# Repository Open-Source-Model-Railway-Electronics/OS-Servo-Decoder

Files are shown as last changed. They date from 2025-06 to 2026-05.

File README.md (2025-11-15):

# OS-Servo-Decoder

The OS-Servo-Decoder is a simple and robust DCC accessory decoder designed for driving up to 8 servo motors. It supports modern model railroads with flexible configuration options, external relay modules for polarity switching (optional) and direct control using both input switches, DCC accessory commands and locomotive functions (F1–F8).

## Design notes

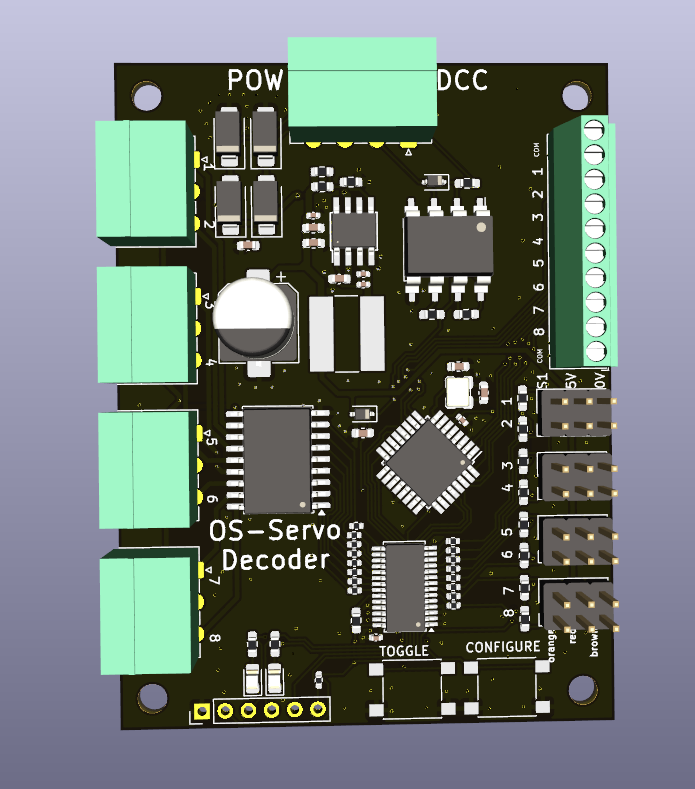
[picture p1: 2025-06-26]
hardware/OS-Servo-Decoder-8.png

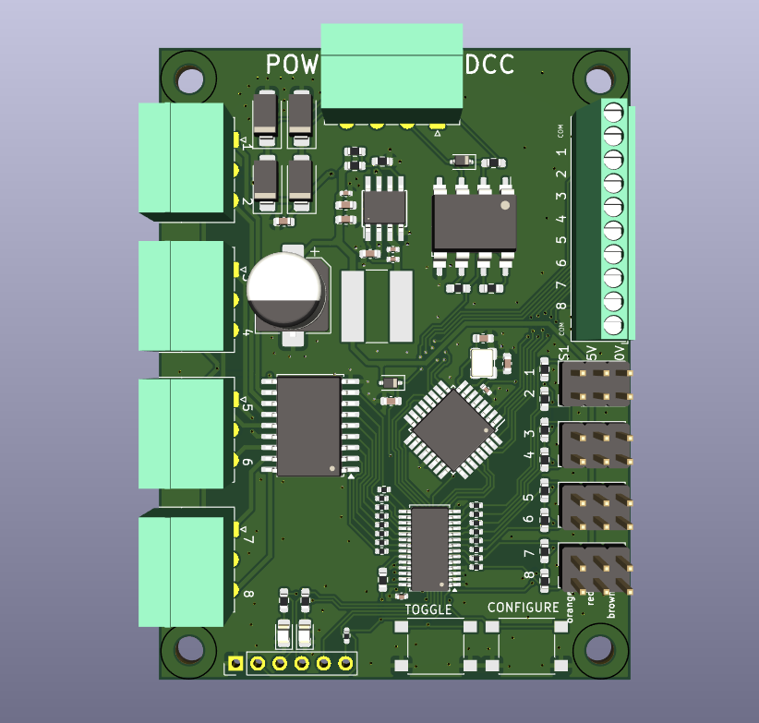
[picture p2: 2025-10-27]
releases/OS-Servo-Decoder-8.png

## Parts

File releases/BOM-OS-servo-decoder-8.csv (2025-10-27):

Comment | Designator | Footprint | LCSC
6N137 | U1001 | SOP-8_6.62x9.15mm_P2.54mm | C110020
Crystal_GND2 | Y201 | crystal_arduino | C13738
100nF | C501 | C_0603_1608Metric | C14663
ATmega328-A | U202 | TQFP-32_7x7mm_P0.8mm | C14877
22nF | C903 | C_0402_1005Metric | C1532
ULN2803A | U1101 | SOIC-18W_7.5x11.6mm_P1.27mm | C181731
1k | R1001 | R_0603_smalltext | C21190
1N4148WS | D1001,D401 | D_SOD-323 | C2128
150k | R903 | R_0603_1608Metric | C22807
220k | R901 | R_0603_1608Metric | C22961
220R | R1602,R1603,R1604,R1605,R1606,R1607,R1608,R1609,R1610,R1611,R1612,R1613,R1614,R1615,R1616,R1617 | R_0402_1005Metric | C25091
10k | R202 | R_0402_1005Metric_Pad0.72x0.64mm_HandSolder | C25744
10k | R1002,R1003,R1004,R1005,R1601,R701,R702,R801,R802,R904,R905 | R_0603_smalltext | C25804
PCA9685PW | U1601 | TSSOP-28_4.4x9.7mm_P0.65mm | C2678753
L | L901 | L_Bourns-SRN8040_8x8.15mm | C2929438
SW_Push | SW601,SW602 | tactile_SMD_6mm | C294567
MT2499A | U901 | TI_SO-PowerPAD-8 | C3007555
100nF | C1601,C202,C902,C906 | C_0402_1005Metric | C307331
12pF | C201,C203 | C_0603_1608Metric | C38523
6k2 | R201,R203 | R_0603_1608Metric_Pad0.98x0.95mm_HandSolder | C4260
20k | R902 | R_0603_1608Metric | C4328
22uF | C402,C901,C904,C905 | C_0603_1608Metric | C45783
1000uF | C401 | CP_Elec_8x10.5 | C5162347
Conn_02x03_Odd_Even | J1001,J701,J801,J901 | PinHeader_2x03_P2.54mm_Vertical | C65114
LED | D201,D202 | LED_0805_2012Metric_Pad1.15x1.40mm_HandSolder | C84256
SS53 | D501,D502,D503,D504 | D_SMA | C8678
Screw_Terminal_01x03 | J1301,J1401,J1501,J401 | PhoenixContact_MC_1,5_3-G-3.5_1x03_P3.50mm_Horizontal | C880573
FEMALE | J101 | PhoenixContact_MC_1,5_4-G-3.5_1x04_P3.50mm_Horizontal | C880574
Screw_Terminal_01x10 | J501 | TerminalBlock_Phoenix_MPT-0,5-10-2.54_1x10_P2.54mm_Horizontal

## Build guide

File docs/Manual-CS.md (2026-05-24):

> 🌐 &nbsp; [🇬🇧 EN](Manual-EN.md) &nbsp;|&nbsp; [🇩🇪 DE](Manual-DE.md) &nbsp;|&nbsp; [🇫🇷 FR](Manual-FR.md) &nbsp;|&nbsp; [🇳🇱 NL](Manual-NL.md) &nbsp;|&nbsp; [🇪🇸 ES](Manual-ES.md) &nbsp;|&nbsp; [🇮🇹 IT](Manual-IT.md) &nbsp;|&nbsp; [🇵🇱 PL](Manual-PL.md) &nbsp;|&nbsp; 🇨🇿 CS &nbsp;|&nbsp; [🇩🇰 DA](Manual-DA.md) &nbsp;|&nbsp; [🇳🇴 NO](Manual-NO.md) &nbsp;|&nbsp; [🇸🇪 SV](Manual-SV.md) &nbsp;|&nbsp; [🇭🇺 HU](Manual-HU.md) &nbsp;|&nbsp; [🇵🇹 PT](Manual-PT.md)

# Manuál dekodérů OS-Servo

## 📘 Úvod
OS-Servo-Decoder je jednoduchý a robustní DCC příslušenský dekodér navržený pro pohon až 8 servomotorů. Podporuje moderní modelové železnice s flexibilními možnostmi konfigurace, externími relé moduly pro přepínání polarity (volitelné) a přímé ovládání pomocí vstupních přepínačů, DCC příslušenských příkazů i lokomotivních funkcí (F1–F8).

---

## 📚 Obsah

- [Manuál dekodérů OS-Servo](#manuál-dekodérů-os-servo)
  - [📘 Úvod](#-úvod)
  - [📚 Obsah](#-obsah)
  - [🔧 Vlastnosti](#-vlastnosti)
  - [🔌 Připojení dekodéru](#-připojení-dekodéru)
  - [💪 Ovládání výstupů servo](#-ovládání-výstupů-servo)
  - [🛠️ Konfigurační režim DCC](#️-konfigurační-režim-dcc)
  - [🛠️ Konfigurační režim tlačítek](#️-konfigurační-režim-tlačítek)
  - [🌟 Ukládání poloh serva](#-ukládání-poloh-serva)
  - [🚗 Režimy lokomotivních funkcí](#-režimy-lokomotivních-funkcí)
  - [⚖️ Adresový offset](#️-adresový-offset)
  - [⏰ Režim automatického přepínání](#-režim-automatického-přepínání)
  - [📊 Souhrn](#-souhrn)

---

## 🔧 Vlastnosti
- Ovládá až 8 serv  
- Používá zásuvné šroubové svorky pro snadné zapojení  
- Externí relé moduly  
- Plná podpora:  
  - Standardní pohyb výhybky  
  - Přepínání polarity (kde je podporováno)  
  - Nastavitelné krajní polohy serva (pomocí tlačítek)  
- Samostatná konfigurace: není potřeba PC, CV ani programátor  
- Volitelné ovládání lokomotivními funkcemi DCC (F1–F18)  
- Podporuje Roco 4-adresový offset  

---

## 🔌 Připojení dekodéru

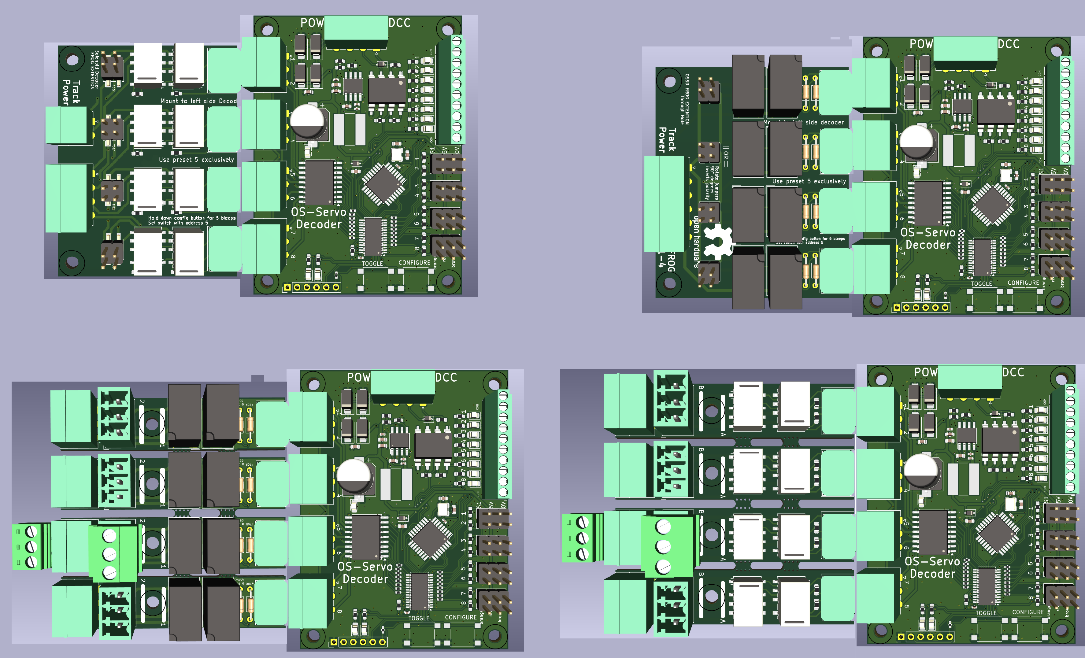
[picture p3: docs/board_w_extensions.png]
OS-Servo-Decoder-8 s různými konfiguracemi rozšiřujících relé


*OS-Servo-Decoder-8 zobrazený s různými zapojenými rozšiřujícími relé moduly (vlevo nahoře: aretační relé; vpravo nahoře: víceúčelová relé; dole: kombinace s připojenými servy).*

OS-Servo-Decoder-8 používá stejné schéma zapojení jako OS-Solenoid-Decoder:

- **Horní záhlaví (POW / DCC):** Připojte kolejové napětí DCC nebo DC napájení (max. 19 V)
- ⚠️ **Důležité:** Nepoužívejte AC napětí — poškodí dekodér
- **Záhlaví pro serva (pravá strana):** Připojte každý servomotor ke 3-pinovému konektoru
  - Standardní zapojení: **GND — +5 V — Signál**
- **Relé konektory (levá strana):** A, COM, B — pro rozšiřující OS relé moduly

---

## 💪 Ovládání výstupů servo

Každý výstup serva je řízen DCC příslušenskou adresou. Když dekodér přijme DCC příkaz pro přiřazenou adresu, plynule posune servo do uložené polohy pro daný stav příkazu (PŘÍMÝ nebo OBLOUK).

- Odeslání příkazu **PŘÍMÝ** přesune servo do uložené přímé krajní polohy.
- Odeslání příkazu **OBLOUK** přesune servo do uložené obloukové krajní polohy.
- Pokud jsou namontovány rozšiřující relé moduly, kontakty relé se přepínají synchronně se servem pro polarizaci srdcovky.

Krajní polohy serva se ukládají pomocí funkčních kláves lokomotivy — viz [Ukládání poloh serva](#-ukládání-poloh-serva) níže.

---

## 🛠️ Konfigurační režim DCC

Dekodér podporuje konfigurační režim, který funguje zcela z vašeho DCC ovladače — není potřeba počítač ani programátor CV.

Pro vstup do konfiguračního režimu vyberte na ovladači adresu lokomotivy **9999** a nastavte **F0, F1 a F2 vše na VYPNUTO**. Dekodér vstoupí do konfiguračního režimu a přijme příkazy funkčních kláves.

Po vstupu do konfiguračního režimu použijte funkční klávesy (F1–F8) pro nastavení možností popsaných v níže uvedených sekcích. Stiskněte **F0 = VYPNUTO** pro ukončení a návrat do normálního provozu.

---

## 🛠️ Konfigurační režim tlačítek

Deska má dvě fyzická tlačítka: **CONFIGURE** (KONFIGUROVAT) a **TOGGLE** (PŘEPNOUT).

- **CONFIGURE** — přímo vstoupí do konfiguračního režimu bez potřeby ovladače. Dekodér reaguje LED signalizací indikující aktivní nastavení.
- **TOGGLE** — ručně přepne aktuálně vybraný výstup serva mezi jeho dvěma uloženými polohami. Užitečné pro testování pohybu a nastavení krajních poloh.

---

## 🌟 Ukládání poloh serva
V provozním režimu použijte tyto funkce k programování:

- **F1 = ZAP ➔** Uloží aktuální polohu jako *OBLOUK*  
- **F2 = ZAP ➔** Uloží aktuální polohu jako *PŘÍMÝ*  
- **F3 = ZAP ➔** Invertuje relé srdcovky *(pouze model s 6 relé)*  
- **F0 = VYP ➔** Ukončí provozní režim  

---

## 🚗 Režimy lokomotivních funkcí
V konfiguračním režimu můžete zvolit ovládání dekodéru pomocí lokomotivních funkčních kláves místo příslušenských příkazů.

- **F4 = ZAP ➔** Zakáže ovládání lokomotivou *(výchozí)*  
- **F5 = ZAP ➔** Povolí režim lokomotivních funkcí *(F1–F8)* — používá 1 adresu  
- **F6 = ZAP ➔** Povolí 4-funkční režim *(F1–F4)* — používá 2 adresy  

To umožňuje velmi rychlé přepínání pomocí ovladačů jako Roco Lokmaus nebo Multimaus.

---

## ⚖️ Adresový offset
Pro kompenzaci offsetu Roco o 4 použijte:

- **F7 = ZAP ➔** Povolí 4-adresový offset  

---

## ⏰ Režim automatického přepínání
Povolte automatické přepínání vybraného motoru:

- **F8 = ZAP ➔** Motor se přepíná každých 5 sekund  
  - Rychlost je řízena ovladačem  
  - Směr ovladače nehraje roli  
  - Ovladač 0 = pomalu, Maximum = rychle  

V tomto režimu motor již není řízen funkčními klávesami ovladače.

---

## 📊 Souhrn
- Použijte tlačítka pro přímé nastavení a nastavení serva  
- Použijte DCC adresu lokomotivy **9999** s **F0, F1, F2 VYPNUTO** pro vstup do konfiguračního režimu  
- Použijte **F1/F2** pro uložení poloh serva  
- Použijte **F4–F8** pro povolení ovládání lokomotivními funkcemi, adresového offsetu nebo režimů přepínání  

Všechny OS-Servo-Decoders sdílejí toto rozhraní a logiku.  
Není potřeba počítač. Žádné CV. Stačí zapojit, adresovat a spustit.

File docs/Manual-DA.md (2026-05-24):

> 🌐 &nbsp; [🇬🇧 EN](Manual-EN.md) &nbsp;|&nbsp; [🇩🇪 DE](Manual-DE.md) &nbsp;|&nbsp; [🇫🇷 FR](Manual-FR.md) &nbsp;|&nbsp; [🇳🇱 NL](Manual-NL.md) &nbsp;|&nbsp; [🇪🇸 ES](Manual-ES.md) &nbsp;|&nbsp; [🇮🇹 IT](Manual-IT.md) &nbsp;|&nbsp; [🇵🇱 PL](Manual-PL.md) &nbsp;|&nbsp; [🇨🇿 CS](Manual-CS.md) &nbsp;|&nbsp; 🇩🇰 DA &nbsp;|&nbsp; [🇳🇴 NO](Manual-NO.md) &nbsp;|&nbsp; [🇸🇪 SV](Manual-SV.md) &nbsp;|&nbsp; [🇭🇺 HU](Manual-HU.md) &nbsp;|&nbsp; [🇵🇹 PT](Manual-PT.md)

# OS-Servo-Decoders Manual

## 📘 Introduktion
OS-Servo-Decoder er en enkel og robust DCC-tilbehørsdekoder designet til at drive op til 8 servomotorer. Den understøtter moderne modeljernbaner med fleksible konfigurationsmuligheder, eksterne relæmoduler til polaritetsskift (valgfrit) og direkte styring ved hjælp af både indgangsafbrydere, DCC-tilbehørskommandoer og lokomotivfunktioner (F1–F8).

---

## 📚 Indholdsfortegnelse

- [OS-Servo-Decoders Manual](#os-servo-decoders-manual)
  - [📘 Introduktion](#-introduktion)
  - [📚 Indholdsfortegnelse](#-indholdsfortegnelse)
  - [🔧 Egenskaber](#-egenskaber)
  - [🔌 Tilslutning af dekoderen](#-tilslutning-af-dekoderen)
  - [💪 Styring af servo-udgange](#-styring-af-servo-udgange)
  - [🛠️ DCC-konfigurationstilstand](#️-dcc-konfigurationstilstand)
  - [🛠️ Knapkonfigurationstilstand](#️-knapkonfigurationstilstand)
  - [🌟 Lagring af servo-positioner](#-lagring-af-servo-positioner)
  - [🚗 Lokomotivfunktionstilstande](#-lokomotivfunktionstilstande)
  - [⚖️ Adresseforskydning](#️-adresseforskydning)
  - [⏰ Auto-toggle-tilstand](#-auto-toggle-tilstand)
  - [📊 Oversigt](#-oversigt)

---

## 🔧 Egenskaber
- Styrer op til 8 servoer  
- Bruger tilsluttbare skrueterminaler til nem kabeltrækning  
- Eksterne relæmoduler  
- Understøtter fuldt ud:  
  - Standard sporskiftebevægelse  
  - Polaritetsskift (hvor understøttet)  
  - Justerbare servo-endpositioner (via knapper)  
- Selvstændig konfiguration: ingen PC, CV'er eller programmere påkrævet  
- Valgfri DCC-lokomotivfunktionsstyring (F1–F18)  
- Understøtter Roco 4-adresse-forskydning  

---

## 🔌 Tilslutning af dekoderen

OS-Servo-Decoder-8 med forskellige relæudvidelseskonfigurationer

*OS-Servo-Decoder-8 vist med forskellige relæudvidelsesmoduler tilsluttet (øverst til venstre: selvholdende relæer; øverst til højre: general-purpose relæer; nederst: kombinationer med servoer tilsluttet).*

OS-Servo-Decoder-8 bruger det samme kabeltrækningslayout som OS-Solenoid-Decoder:

- **Øvre header (POW / DCC):** Forbind enten DCC-skinnesænkning eller en DC-strømforsyning (maks. 19 V)
- ⚠️ **Vigtigt:** Brug ikke AC-spænding — dette vil beskadige dekoderen
- **Servo-headere (højre side):** Forbind hver servomotor til 3-pin-stikket
  - Standard pinout: **GND — +5 V — Signal**
- **Relæstik (venstre side):** A, COM, B — til OS-relæudvidelsesmoduler

---

## 💪 Styring af servo-udgange

Hver servo-udgang styres af en DCC-tilbehørsadresse. Når dekoderen modtager en DCC-kommando for en tildelt adresse, bevæger den servoens jævnt til den lagrede position for den kommandotilstand (LIGE eller KURVET).

- Afsendelse af **LIGE**-kommandoen bevæger servoens til dens lagrede lige endposition.
- Afsendelse af **KURVET**-kommandoen bevæger servoens til dens lagrede kurvede endposition.
- Hvis relæudvidelsesmoduler er monteret, skifter relækontakterne synkront med servoens til hjertestykke-polarisering.

Servo-endpositioner lagres ved hjælp af lokomotivfunktionsknapper — se [Lagring af servo-positioner](#-lagring-af-servo-positioner) nedenfor.

---

## 🛠️ DCC-konfigurationstilstand

Dekoderen understøtter en konfigurationstilstand, der fungerer udelukkende fra din DCC-styreenhed — ingen computer, ingen CV-programmer påkrævet.

For at gå ind i konfigurationstilstand, vælg lokomotivadresse **9999** på din styreenhed og sæt **F0, F1 og F2 alle til FRA**. Dekoderen vil gå ind i konfigurationstilstand og acceptere funktionstastskommandoer.

Når du er i konfigurationstilstand, bruges funktionstasterne (F1–F8) til at indstille muligheder som beskrevet i afsnittene nedenfor. Tryk på **F0 = FRA** for at afslutte og vende tilbage til normal drift.

---

## 🛠️ Knapkonfigurationstilstand

Kortet har to fysiske knapper: **CONFIGURE** og **TOGGLE**.

- **CONFIGURE** — går direkte ind i konfigurationstilstand uden behov for en styreenhed. Dekoderen reagerer med LED-tilbagemelding, der angiver den aktive indstilling.
- **TOGGLE** — skifter manuelt den aktuelt valgte servo-udgang mellem dens to lagrede positioner. Nyttigt til test af bevægelse og justering af endpositioner.

---

## 🌟 Lagring af servo-positioner
Mens du er i Kørselstilstand, brug disse funktioner til at programmere:

- **F1 = TIL ➔** Gem aktuel position som *KURVET*  
- **F2 = TIL ➔** Gem aktuel position som *LIGE*  
- **F3 = TIL ➔** Inverter frog-relæet *(kun 6-relæ-model)*  
- **F0 = FRA ➔** Afslut kørselstilstand  

---

## 🚗 Lokomotivfunktionstilstande
I konfigurationstilstand kan du vælge at styre dekoderen ved hjælp af lokomotivfunktionsknapper i stedet for tilbehørskommandoer.

- **F4 = TIL ➔** Deaktiver lokomotivsstyring *(standard)*  
- **F5 = TIL ➔** Aktiver lokomotivsfunktionstilstand *(F1–F8)* — bruger 1 adresse  
- **F6 = TIL ➔** Aktiver 4-funktionstilstand *(F1–F4)* — bruger 2 adresser  

Dette muliggør ultrahurtig skift ved brug af styrenheder som Roco Lokmaus eller Multimaus.

---

## ⚖️ Adresseforskydning
For at kompensere for Rocos forskydning på 4, brug:

- **F7 = TIL ➔** Aktiver 4-adresse-forskydning  

---

## ⏰ Auto-toggle-tilstand
Aktiver automatisk toggling af en valgt motor:

- **F8 = TIL ➔** Motor skifter hvert 5. sekund  
  - Hastighed styres af styreenheden  
  - Styrenheds-retning er ligegyldig  
  - Styreenhed 0 = langsom, Maks = hurtig  

I denne tilstand er motoren ikke længere slavebundet til styrenheds-funktionstaster.

---

## 📊 Oversigt
- Brug knapperne til direkte opsætning og servo-justering  
- Brug DCC-lokomotivadresse **9999** med **F0, F1, F2 FRA** for at gå ind i konfigurationstilstand  
- Brug **F1/F2** til at lagre servo-positioner  
- Brug **F4–F8** til at aktivere lokomotivfunktionsstyring, adresseforskydning eller toggle-tilstande  

Alle OS-Servo-dekodere deler denne grænseflade og logik.  
Ingen computer påkrævet. Ingen CV'er. Bare kabelforbind den, adressér den og kør.

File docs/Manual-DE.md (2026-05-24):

> 🌐 &nbsp; [🇬🇧 EN](Manual-EN.md) &nbsp;|&nbsp; 🇩🇪 DE &nbsp;|&nbsp; [🇫🇷 FR](Manual-FR.md) &nbsp;|&nbsp; [🇳🇱 NL](Manual-NL.md) &nbsp;|&nbsp; [🇪🇸 ES](Manual-ES.md) &nbsp;|&nbsp; [🇮🇹 IT](Manual-IT.md) &nbsp;|&nbsp; [🇵🇱 PL](Manual-PL.md) &nbsp;|&nbsp; [🇨🇿 CS](Manual-CS.md) &nbsp;|&nbsp; [🇩🇰 DA](Manual-DA.md) &nbsp;|&nbsp; [🇳🇴 NO](Manual-NO.md) &nbsp;|&nbsp; [🇸🇪 SV](Manual-SV.md) &nbsp;|&nbsp; [🇭🇺 HU](Manual-HU.md) &nbsp;|&nbsp; [🇵🇹 PT](Manual-PT.md)

# OS-Servo-Decoder Handbuch

## 📘 Einführung
Der OS-Servo-Decoder ist ein einfacher und robuster DCC-Zubehördecoder für die Steuerung von bis zu 8 Servomotoren. Er unterstützt moderne Modellbahnen mit flexiblen Konfigurationsmöglichkeiten, externen Relaismodulen für Polaritätsumschaltung (optional) und direkter Steuerung über Eingangsschalter, DCC-Zubehörbefehle und Lokfunktionen (F1–F8).

---

## 📚 Inhaltsverzeichnis

- [OS-Servo-Decoder Handbuch](#os-servo-decoder-handbuch)
  - [📘 Einführung](#-einführung)
  - [📚 Inhaltsverzeichnis](#-inhaltsverzeichnis)
  - [🔧 Merkmale](#-merkmale)
  - [🔌 Anschließen des Decoders](#-anschließen-des-decoders)
  - [💪 Steuerung der Servoausgänge](#-steuerung-der-servoausgänge)
  - [🛠️ DCC-Konfigurationsmodus](#️-dcc-konfigurationsmodus)
  - [🛠️ Tasten-Konfigurationsmodus](#️-tasten-konfigurationsmodus)
  - [🌟 Speichern von Servopositionen](#-speichern-von-servopositionen)
  - [🚗 Lokfunktionsmodi](#-lokfunktionsmodi)
  - [⚖️ Adress-Offset](#️-adress-offset)
  - [⏰ Automatischer Umschaltmodus](#-automatischer-umschaltmodus)
  - [📊 Zusammenfassung](#-zusammenfassung)

---

## 🔧 Merkmale
- Steuert bis zu 8 Servos  
- Verwendet steckbare Schraubklemmen für einfache Verdrahtung  
- Externe Relaismodule  
- Vollständige Unterstützung für:  
  - Standardmäßige Weichenbewegung  
  - Polaritätsumschaltung (wo unterstützt)  
  - Einstellbare Servo-Endpositionen (über Tasten)  
- Eigenständige Konfiguration: kein PC, keine CVs oder Programmierer erforderlich  
- Optionale DCC-Lokfunktionssteuerung (F1–F18)  
- Unterstützt Roco 4-Adress-Offset  

---

## 🔌 Anschließen des Decoders

OS-Servo-Decoder-8 mit verschiedenen Relaiserweiterungs-Konfigurationen

*Der OS-Servo-Decoder-8 mit verschiedenen eingesteckten Relaiserweiterungsmodulen (oben links: bistabile Relais; oben rechts: Universalrelais; unten: Kombinationen mit angeschlossenen Servos).*

Der OS-Servo-Decoder-8 verwendet dasselbe Verdrahtungsschema wie der OS-Solenoid-Decoder:

- **Obere Stiftleiste (POW / DCC):** Entweder DCC-Gleisspannung oder eine DC-Stromversorgung anschließen (max. 19 V)
- ⚠️ **Wichtig:** Keine Wechselspannung verwenden — dies beschädigt den Decoder
- **Servo-Stiftleisten (rechte Seite):** Jeden Servomotor an den 3-poligen Stecker anschließen
  - Standardbelegung: **GND — +5 V — Signal**
- **Relais-Stecker (linke Seite):** A, COM, B — für OS-Relaiserweiterungsmodule

---

## 💪 Steuerung der Servoausgänge

Jeder Servoausgang wird durch eine DCC-Zubehöradresse gesteuert. Wenn der Decoder einen DCC-Befehl für eine zugewiesene Adresse empfängt, bewegt er den Servo gleichmäßig zur gespeicherten Position für diesen Befehlszustand (GERADE oder GEBOGEN).

- Das Senden des **GERADE**-Befehls bewegt den Servo zu seiner gespeicherten geraden Endposition.
- Das Senden des **GEBOGEN**-Befehls bewegt den Servo zu seiner gespeicherten gebogenen Endposition.
- Wenn Relaiserweiterungsmodule eingebaut sind, schalten die Relaiskontakte synchron mit dem Servo für die Herzstück-Polarisierung.

Servo-Endpositionen werden mit Lokfunktionstasten gespeichert — siehe [Speichern von Servopositionen](#-speichern-von-servopositionen) unten.

---

## 🛠️ DCC-Konfigurationsmodus

Der Decoder unterstützt einen Konfigurationsmodus, der vollständig über dein DCC-Fahrgerät funktioniert — kein Computer, kein CV-Programmierer erforderlich.

Um den Konfigurationsmodus aufzurufen, Lokadresse **9999** am Fahrgerät wählen und **F0, F1 und F2 alle auf AUS** stellen. Der Decoder wechselt in den Konfigurationsmodus und akzeptiert Funktionstastenbefehle.

Im Konfigurationsmodus die Funktionstasten (F1–F8) verwenden, um Optionen wie in den folgenden Abschnitten beschrieben einzustellen. **F0 = AUS** drücken, um zu beenden und zum Normalbetrieb zurückzukehren.

---

## 🛠️ Tasten-Konfigurationsmodus

Die Platine hat zwei physische Tasten: **CONFIGURE** und **TOGGLE**.

- **CONFIGURE** — wechselt direkt in den Konfigurationsmodus, ohne ein Fahrgerät zu benötigen. Der Decoder antwortet mit LED-Feedback, das die aktive Einstellung anzeigt.
- **TOGGLE** — schaltet den aktuell ausgewählten Servoausgang manuell zwischen seinen beiden gespeicherten Positionen um. Nützlich zum Testen der Bewegung und zum Anpassen der Endpositionen.

---

## 🌟 Speichern von Servopositionen
Im Fahrmodus diese Funktionen zum Programmieren verwenden:

- **F1 = EIN ➔** Aktuelle Position als *GEBOGEN* speichern  
- **F2 = EIN ➔** Aktuelle Position als *GERADE* speichern  
- **F3 = EIN ➔** Frog-Relais invertieren *(nur 6-Relais-Modell)*  
- **F0 = AUS ➔** Fahrmodus beenden  

---

## 🚗 Lokfunktionsmodi
Im Konfigurationsmodus kann gewählt werden, den Decoder über Lokfunktionstasten anstelle von Zubehörbefehlen zu steuern.

- **F4 = EIN ➔** Lok-Steuerung deaktivieren *(Standard)*  
- **F5 = EIN ➔** Lokfunktionsmodus aktivieren *(F1–F8)* — verwendet 1 Adresse  
- **F6 = EIN ➔** 4-Funktions-Modus aktivieren *(F1–F4)* — verwendet 2 Adressen  

Dies ermöglicht ultraschnelles Schalten mit Fahrgeräten wie Roco Lokmaus oder Multimaus.

---

## ⚖️ Adress-Offset
Um Rocos Offset von 4 zu kompensieren, verwenden:

- **F7 = EIN ➔** 4-Adress-Offset aktivieren  

---

## ⏰ Automatischer Umschaltmodus
Automatisches Umschalten eines ausgewählten Motors aktivieren:

- **F8 = EIN ➔** Motor schaltet alle 5 Sekunden um  
  - Geschwindigkeit wird durch das Fahrgerät gesteuert  
  - Fahrtrichtung des Fahrgeräts spielt keine Rolle  
  - Fahrgerät 0 = langsam, Maximum = schnell  

In diesem Modus ist der Motor nicht mehr an die Funktionstaten des Fahrgeräts gebunden.

---

## 📊 Zusammenfassung
- Tasten für direkte Einrichtung und Servo-Anpassung verwenden  
- DCC-Lokadresse **9999** mit **F0, F1, F2 AUS** verwenden, um den Konfigurationsmodus aufzurufen  
- **F1/F2** zum Speichern von Servopositionen verwenden  
- **F4–F8** zum Aktivieren von Lokfunktionssteuerung, Adress-Offset oder Umschaltmodi verwenden  

Alle OS-Servo-Decoder teilen diese Schnittstelle und Logik.  
Kein Computer erforderlich. Keine CVs. Einfach verkabeln, adressieren und fahren.

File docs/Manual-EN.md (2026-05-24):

> 🌐 &nbsp; 🇬🇧 EN &nbsp;|&nbsp; [🇩🇪 DE](Manual-DE.md) &nbsp;|&nbsp; [🇫🇷 FR](Manual-FR.md) &nbsp;|&nbsp; [🇳🇱 NL](Manual-NL.md) &nbsp;|&nbsp; [🇪🇸 ES](Manual-ES.md) &nbsp;|&nbsp; [🇮🇹 IT](Manual-IT.md) &nbsp;|&nbsp; [🇵🇱 PL](Manual-PL.md) &nbsp;|&nbsp; [🇨🇿 CS](Manual-CS.md) &nbsp;|&nbsp; [🇩🇰 DA](Manual-DA.md) &nbsp;|&nbsp; [🇳🇴 NO](Manual-NO.md) &nbsp;|&nbsp; [🇸🇪 SV](Manual-SV.md) &nbsp;|&nbsp; [🇭🇺 HU](Manual-HU.md) &nbsp;|&nbsp; [🇵🇹 PT](Manual-PT.md)

# OS-Servo-Decoders Manual

## 📘 Introduction
The OS-Servo-Decoder is a simple and robust DCC accessory decoder designed for driving up to 8 servo motors. It supports modern model railroads with flexible configuration options, external relay modules for polarity switching (optional) and direct control using both input switches, DCC accessory commands and locomotive functions (F1–F8).

---

## 📚 Table of Contents

- [OS-Servo-Decoders Manual](#os-servo-decoders-manual)
  - [📘 Introduction](#-introduction)
  - [📚 Table of Contents](#-table-of-contents)
  - [🔧 Features](#-features)
  - [🔌 Connecting the Decoder](#-connecting-the-decoder)
  - [💪 Controlling the Servo Outputs](#-controlling-the-servo-outputs)
  - [🛠️ DCC Configuration Mode](#️-dcc-configuration-mode)
  - [🛠️ Button Configuration Mode](#️-button-configuration-mode)
  - [🌟 Storing Servo Positions](#-storing-servo-positions)
  - [🚗 Loco Function Modes](#-loco-function-modes)
  - [⚖️ Address Offset](#️-address-offset)
  - [⏰ Auto-Toggle Mode](#-auto-toggle-mode)
  - [📊 Summary](#-summary)

---

## 🔧 Features
- Controls up to 8 servos  
- Uses pluggable screw terminals for easy wiring  
- External relay modules  
- Fully supports:  
  - Standard turnout movement  
  - Polarity switching (where supported)  
  - Adjustable servo end positions (via buttons)  
- Standalone configuration: no PC, CVs or programmers required  
- Optional DCC locomotive function control (F1–F18)  
- Supports Roco 4-address offset  

---

## 🔌 Connecting the Decoder

OS-Servo-Decoder-8 with different relay extension configurations

*The OS-Servo-Decoder-8 shown with various relay extension modules plugged in (top-left: latching relays; top-right: general-purpose relays; bottom: combinations with servos connected).*

The OS-Servo-Decoder-8 uses the same wiring layout as the OS-Solenoid-Decoder:

- **Top header (POW / DCC):** Connect either DCC track voltage or a DC power supply (max 19 V)
- ⚠️ **Important:** Do not use AC voltage — this will damage the decoder
- **Servo headers (right side):** Connect each servo motor to the 3-pin connector
  - Standard pinout: **GND — +5 V — Signal**
- **Relay connectors (left side):** A, COM, B — for OS relay extension modules

---

## 💪 Controlling the Servo Outputs

Each servo output is controlled by a DCC accessory address. When the decoder receives a DCC command for an assigned address, it moves the servo smoothly to the stored position for that command state (STRAIGHT or CURVED).

- Sending the **STRAIGHT** command moves the servo to its stored straight end position.
- Sending the **CURVED** command moves the servo to its stored curved end position.
- If relay extension modules are fitted, the relay contacts switch in sync with the servo for frog polarization.

Servo end positions are stored using loco function keys — see [Storing Servo Positions](#-storing-servo-positions) below.

---

## 🛠️ DCC Configuration Mode

The decoder supports a configuration mode that works entirely from your DCC throttle — no computer, no CV programmer required.

To enter configuration mode, select loco address **9999** on your throttle and set **F0, F1, and F2 all to OFF**. The decoder will enter config mode and accept function key commands.

Once in config mode, use the function keys (F1–F8) to set options as described in the sections below. Press **F0 = OFF** to exit and return to normal operation.

---

## 🛠️ Button Configuration Mode

The board has two physical buttons: **CONFIGURE** and **TOGGLE**.

- **CONFIGURE** — enters configuration mode directly, without needing a throttle. The decoder responds with LED feedback indicating the active setting.
- **TOGGLE** — manually toggles the currently selected servo output between its two stored positions. Useful for testing movement and adjusting end positions.

---

## 🌟 Storing Servo Positions
While in Run Mode, use these functions to program:

- **F1 = ON ➔** Save current position as *CURVED*  
- **F2 = ON ➔** Save current position as *STRAIGHT*  
- **F3 = ON ➔** Invert frog relay *(6-relay model only)*  
- **F0 = OFF ➔** Exit Run Mode  

---

## 🚗 Loco Function Modes
In Config Mode, you can choose to control the decoder using loco function keys instead of accessory commands.

- **F4 = ON ➔** Disable loco control *(default)*  
- **F5 = ON ➔** Enable loco function mode *(F1–F8)* — uses 1 address  
- **F6 = ON ➔** Enable 4-function mode *(F1–F4)* — uses 2 addresses  

This allows ultra-fast switching using throttles like Roco Lokmaus or Multimaus.

---

## ⚖️ Address Offset
To compensate for Roco’s offset of 4, use:

- **F7 = ON ➔** Enable 4-address offset  

---

## ⏰ Auto-Toggle Mode
Enable auto-toggling of a selected motor:

- **F8 = ON ➔** Motor toggles every 5 seconds  
  - Speed is controlled by throttle  
  - Throttle direction does not matter  
  - Throttle 0 = slow, Max = fast  

In this mode, the motor is no longer slaved to throttle function keys.

---

## 📊 Summary
- Use the buttons for direct setup and servo adjustment  
- Use DCC loco address **9999** with **F0, F1, F2 OFF** to enter config mode  
- Use **F1/F2** to store servo positions  
- Use **F4–F8** to enable loco function control, address offset or toggle modes  

All OS-Servo-Decoders share this interface and logic.  
No computer needed. No CVs. Just wire it, address it, and run it.

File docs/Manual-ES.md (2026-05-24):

> 🌐 &nbsp; [🇬🇧 EN](Manual-EN.md) &nbsp;|&nbsp; [🇩🇪 DE](Manual-DE.md) &nbsp;|&nbsp; [🇫🇷 FR](Manual-FR.md) &nbsp;|&nbsp; [🇳🇱 NL](Manual-NL.md) &nbsp;|&nbsp; 🇪🇸 ES &nbsp;|&nbsp; [🇮🇹 IT](Manual-IT.md) &nbsp;|&nbsp; [🇵🇱 PL](Manual-PL.md) &nbsp;|&nbsp; [🇨🇿 CS](Manual-CS.md) &nbsp;|&nbsp; [🇩🇰 DA](Manual-DA.md) &nbsp;|&nbsp; [🇳🇴 NO](Manual-NO.md) &nbsp;|&nbsp; [🇸🇪 SV](Manual-SV.md) &nbsp;|&nbsp; [🇭🇺 HU](Manual-HU.md) &nbsp;|&nbsp; [🇵🇹 PT](Manual-PT.md)

# Manual del OS-Servo-Decoder

## 📘 Introducción
El OS-Servo-Decoder es un decodificador de accesorios DCC sencillo y robusto diseñado para accionar hasta 8 servomotores. Ofrece opciones de configuración flexibles para maquetas de ferrocarril modernas, módulos de relé externos para conmutación de polaridad (opcional) y control directo mediante interruptores de entrada, comandos de accesorio DCC y funciones de locomotora (F1–F8).

---

## 📚 Tabla de Contenidos

- [Manual del OS-Servo-Decoder](#manual-del-os-servo-decoder)
  - [📘 Introducción](#-introducción)
  - [📚 Tabla de Contenidos](#-tabla-de-contenidos)
  - [🔧 Características](#-características)
  - [🔌 Conexión del Decodificador](#-conexión-del-decodificador)
  - [💪 Control de las Salidas de Servo](#-control-de-las-salidas-de-servo)
  - [🛠️ Modo de Configuración DCC](#️-modo-de-configuración-dcc)
  - [🛠️ Modo de Configuración por Botón](#️-modo-de-configuración-por-botón)
  - [🌟 Almacenamiento de Posiciones de Servo](#-almacenamiento-de-posiciones-de-servo)
  - [🚗 Modos de Función de Locomotora](#-modos-de-función-de-locomotora)
  - [⚖️ Desplazamiento de Dirección](#️-desplazamiento-de-dirección)
  - [⏰ Modo de Alternancia Automática](#-modo-de-alternancia-automática)
  - [📊 Resumen](#-resumen)

---

## 🔧 Características
- Controla hasta 8 servos  
- Utiliza bornes de tornillo enchufables para un cableado sencillo  
- Módulos de relé externos  
- Compatible completamente con:  
  - Movimiento estándar de agujas  
  - Conmutación de polaridad (donde sea compatible)  
  - Posiciones finales de servo ajustables (mediante botones)  
- Configuración autónoma: no requiere PC, CV ni programadores  
- Control opcional mediante funciones de locomotora DCC (F1–F18)  
- Compatible con el desplazamiento de 4 direcciones de Roco  

---

## 🔌 Conexión del Decodificador

OS-Servo-Decoder-8 con diferentes configuraciones de extensión de relé

*El OS-Servo-Decoder-8 mostrado con varios módulos de extensión de relé enchufados (arriba izquierda: relés enclavados; arriba derecha: relés de uso general; abajo: combinaciones con servos conectados).*

El OS-Servo-Decoder-8 utiliza el mismo esquema de cableado que el OS-Solenoid-Decoder:

- **Cabezal superior (POW / DCC):** Conecte la tensión de vía DCC o una fuente de alimentación DC (máx. 19 V)
- ⚠️ **Importante:** No use tensión AC — esto dañará el decodificador
- **Cabezales de servo (lado derecho):** Conecte cada servomotor al conector de 3 pines
  - Patillaje estándar: **GND — +5 V — Señal**
- **Conectores de relé (lado izquierdo):** A, COM, B — para módulos de extensión de relé OS

---

## 💪 Control de las Salidas de Servo

Cada salida de servo se controla mediante una dirección de accesorio DCC. Cuando el decodificador recibe un comando DCC para una dirección asignada, mueve el servo suavemente hasta la posición almacenada para ese estado de comando (RECTO o CURVO).

- El comando **RECTO** mueve el servo a su posición final recta almacenada.
- El comando **CURVO** mueve el servo a su posición final curva almacenada.
- Si hay módulos de extensión de relé instalados, los contactos del relé conmutan en sincronía con el servo para la polarización del frog.

Las posiciones finales del servo se almacenan usando las teclas de función de locomotora — véase [Almacenamiento de Posiciones de Servo](#-almacenamiento-de-posiciones-de-servo) a continuación.

---

## 🛠️ Modo de Configuración DCC

El decodificador admite un modo de configuración que funciona completamente desde su mando DCC — sin ordenador, sin programador de CV.

Para entrar en el modo de configuración, seleccione la dirección de locomotora **9999** en su mando y ponga **F0, F1 y F2 en OFF**. El decodificador entrará en el modo de configuración y aceptará comandos de tecla de función.

Una vez en el modo de configuración, use las teclas de función (F1–F8) para establecer opciones según se describe en las secciones siguientes. Pulse **F0 = OFF** para salir y volver al funcionamiento normal.

---

## 🛠️ Modo de Configuración por Botón

La placa tiene dos botones físicos: **CONFIGURE** y **TOGGLE**.

- **CONFIGURE** — entra en el modo de configuración directamente, sin necesidad de mando. El decodificador responde con indicación LED que muestra el ajuste activo.
- **TOGGLE** — alterna manualmente la salida de servo seleccionada actualmente entre sus dos posiciones almacenadas. Útil para probar el movimiento y ajustar las posiciones finales.

---

## 🌟 Almacenamiento de Posiciones de Servo
En el Modo de Funcionamiento, use estas funciones para programar:

- **F1 = ON ➔** Guardar posición actual como *CURVO*  
- **F2 = ON ➔** Guardar posición actual como *RECTO*  
- **F3 = ON ➔** Invertir el relé de frog *(solo modelo de 6 relés)*  
- **F0 = OFF ➔** Salir del Modo de Funcionamiento  

---

## 🚗 Modos de Función de Locomotora
En el Modo de Configuración, puede elegir controlar el decodificador usando teclas de función de locomotora en lugar de comandos de accesorio.

- **F4 = ON ➔** Deshabilitar control por locomotora *(predeterminado)*  
- **F5 = ON ➔** Habilitar modo de función de locomotora *(F1–F8)* — usa 1 dirección  
- **F6 = ON ➔** Habilitar modo de 4 funciones *(F1–F4)* — usa 2 direcciones  

Esto permite una conmutación ultrarrápida usando mandos como el Roco Lokmaus o el Multimaus.

---

## ⚖️ Desplazamiento de Dirección
Para compensar el desplazamiento de 4 de Roco, use:

- **F7 = ON ➔** Habilitar desplazamiento de 4 direcciones  

---

## ⏰ Modo de Alternancia Automática
Habilite la alternancia automática de un motor seleccionado:

- **F8 = ON ➔** El motor alterna cada 5 segundos  
  - La velocidad se controla con el regulador  
  - La dirección del regulador no importa  
  - Regulador 0 = lento, Máximo = rápido  

En este modo, el motor ya no está subordinado a las teclas de función del regulador.

---

## 📊 Resumen
- Use los botones para la configuración directa y el ajuste del servo  
- Use la dirección de locomotora DCC **9999** con **F0, F1, F2 en OFF** para entrar en el modo de configuración  
- Use **F1/F2** para almacenar las posiciones del servo  
- Use **F4–F8** para habilitar el control por función de locomotora, el desplazamiento de dirección o los modos de alternancia  

Todos los OS-Servo-Decoders comparten esta interfaz y lógica.  
No se necesita ordenador. Sin CV. Solo cable, dirección y puesta en marcha.

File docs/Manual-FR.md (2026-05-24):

> 🌐 &nbsp; [🇬🇧 EN](Manual-EN.md) &nbsp;|&nbsp; [🇩🇪 DE](Manual-DE.md) &nbsp;|&nbsp; 🇫🇷 FR &nbsp;|&nbsp; [🇳🇱 NL](Manual-NL.md) &nbsp;|&nbsp; [🇪🇸 ES](Manual-ES.md) &nbsp;|&nbsp; [🇮🇹 IT](Manual-IT.md) &nbsp;|&nbsp; [🇵🇱 PL](Manual-PL.md) &nbsp;|&nbsp; [🇨🇿 CS](Manual-CS.md) &nbsp;|&nbsp; [🇩🇰 DA](Manual-DA.md) &nbsp;|&nbsp; [🇳🇴 NO](Manual-NO.md) &nbsp;|&nbsp; [🇸🇪 SV](Manual-SV.md) &nbsp;|&nbsp; [🇭🇺 HU](Manual-HU.md) &nbsp;|&nbsp; [🇵🇹 PT](Manual-PT.md)

# Manuel des décodeurs OS-Servo

## 📘 Introduction
Le OS-Servo-Decoder est un décodeur DCC accessoire simple et robuste conçu pour piloter jusqu'à 8 servomoteurs. Il prend en charge les réseaux ferroviaires miniatures modernes avec des options de configuration flexibles, des modules relais externes pour la commutation de polarité (optionnels) et une commande directe via des interrupteurs d'entrée, des commandes DCC accessoire et des fonctions de locomotive (F1–F8).

---

## 📚 Table des matières

- [Manuel des décodeurs OS-Servo](#manuel-des-décodeurs-os-servo)
  - [📘 Introduction](#-introduction)
  - [📚 Table des matières](#-table-des-matières)
  - [🔧 Caractéristiques](#-caractéristiques)
  - [🔌 Connexion du décodeur](#-connexion-du-décodeur)
  - [💪 Commande des sorties servo](#-commande-des-sorties-servo)
  - [🛠️ Mode de configuration DCC](#️-mode-de-configuration-dcc)
  - [🛠️ Mode de configuration par bouton](#️-mode-de-configuration-par-bouton)
  - [🌟 Mémorisation des positions servo](#-mémorisation-des-positions-servo)
  - [🚗 Modes de fonctions de locomotive](#-modes-de-fonctions-de-locomotive)
  - [⚖️ Décalage d'adresse](#️-décalage-dadresse)
  - [⏰ Mode basculement automatique](#-mode-basculement-automatique)
  - [📊 Récapitulatif](#-récapitulatif)

---

## 🔧 Caractéristiques
- Commande jusqu'à 8 servos  
- Utilise des borniers à vis enfichables pour un câblage facile  
- Modules relais externes  
- Prend entièrement en charge :  
  - Le mouvement standard de l'aiguille  
  - La commutation de polarité (lorsque prise en charge)  
  - Les positions finales de servo réglables (via boutons)  
- Configuration autonome : aucun PC, CV ou programmateur requis  
- Commande optionnelle par fonctions de locomotive DCC (F1–F18)  
- Prend en charge le décalage d'adresse Roco de 4

---

## 🔌 Connexion du décodeur

OS-Servo-Decoder-8 avec différentes configurations d'extension relais

*Le OS-Servo-Decoder-8 présenté avec divers modules d'extension relais branchés (en haut à gauche : relais bistables ; en haut à droite : relais à usage général ; en bas : combinaisons avec servos connectés).*

Le OS-Servo-Decoder-8 utilise la même disposition de câblage que le OS-Solenoid-Decoder :

- **En-tête supérieur (POW / DCC) :** Connectez soit la tension de voie DCC, soit une alimentation DC (max. 19 V)
- ⚠️ **Important :** N'utilisez pas de tension AC — cela endommagerait le décodeur
- **En-têtes servo (côté droit) :** Connectez chaque servomoteur au connecteur 3 broches
  - Brochage standard : **GND — +5 V — Signal**
- **Connecteurs relais (côté gauche) :** A, COM, B — pour les modules d'extension de relais OS

---

## 💪 Commande des sorties servo

Chaque sortie servo est commandée par une adresse DCC accessoire. Lorsque le décodeur reçoit une commande DCC pour une adresse assignée, il déplace le servo en douceur vers la position mémorisée pour cet état de commande (DROITE ou COURBE).

- L'envoi de la commande **DROITE** déplace le servo vers sa position finale droite mémorisée.
- L'envoi de la commande **COURBE** déplace le servo vers sa position finale courbe mémorisée.
- Si des modules d'extension relais sont installés, les contacts relais commutent en synchronisation avec le servo pour la polarisation du cœur.

Les positions finales du servo sont mémorisées à l'aide des touches de fonction de locomotive — voir [Mémorisation des positions servo](#-mémorisation-des-positions-servo) ci-dessous.

---

## 🛠️ Mode de configuration DCC

Le décodeur prend en charge un mode de configuration fonctionnant entièrement depuis votre manette DCC — aucun ordinateur, aucun programmateur CV requis.

Pour entrer en mode de configuration, sélectionnez l'adresse de locomotive **9999** sur votre manette et réglez **F0, F1 et F2 tous sur OFF**. Le décodeur entrera en mode configuration et acceptera les commandes de touches de fonction.

Une fois en mode configuration, utilisez les touches de fonction (F1–F8) pour régler les options décrites dans les sections ci-dessous. Appuyez sur **F0 = OFF** pour quitter et revenir au fonctionnement normal.

---

## 🛠️ Mode de configuration par bouton

La carte comporte deux boutons physiques : **CONFIGURE** et **TOGGLE**.

- **CONFIGURE** — entre directement en mode configuration, sans nécessiter de manette. Le décodeur répond avec un retour LED indiquant le réglage actif.
- **TOGGLE** — bascule manuellement la sortie servo actuellement sélectionnée entre ses deux positions mémorisées. Utile pour tester le mouvement et ajuster les positions finales.

---

## 🌟 Mémorisation des positions servo
En mode de fonctionnement normal, utilisez ces fonctions pour programmer :

- **F1 = ON ➔** Sauvegarder la position actuelle comme *COURBE*  
- **F2 = ON ➔** Sauvegarder la position actuelle comme *DROITE*  
- **F3 = ON ➔** Inverser le relais de cœur *(modèle 6 relais uniquement)*  
- **F0 = OFF ➔** Quitter le mode de fonctionnement  

---

## 🚗 Modes de fonctions de locomotive
En mode configuration, vous pouvez choisir de commander le décodeur en utilisant les touches de fonction de locomotive plutôt que les commandes accessoire.

- **F4 = ON ➔** Désactiver la commande locomotive *(par défaut)*  
- **F5 = ON ➔** Activer le mode fonction locomotive *(F1–F8)* — utilise 1 adresse  
- **F6 = ON ➔** Activer le mode 4 fonctions *(F1–F4)* — utilise 2 adresses  

Cela permet une commutation ultra-rapide avec des manettes comme la Roco Lokmaus ou la Multimaus.

---

## ⚖️ Décalage d'adresse
Pour compenser le décalage de 4 de Roco, utilisez :

- **F7 = ON ➔** Activer le décalage d'adresse de 4  

---

## ⏰ Mode basculement automatique
Activer le basculement automatique d'un moteur sélectionné :

- **F8 = ON ➔** Le moteur bascule toutes les 5 secondes  
  - La vitesse est contrôlée par la manette  
  - Le sens de la manette n'a pas d'importance  
  - Manette à 0 = lent, Maximum = rapide  

Dans ce mode, le moteur n'est plus asservi aux touches de fonction de la manette.

---

## 📊 Récapitulatif
- Utilisez les boutons pour la configuration directe et le réglage des servos  
- Utilisez l'adresse de locomotive DCC **9999** avec **F0, F1, F2 sur OFF** pour entrer en mode configuration  
- Utilisez **F1/F2** pour mémoriser les positions des servos  
- Utilisez **F4–F8** pour activer la commande par fonctions de locomotive, le décalage d'adresse ou les modes de basculement  

Tous les OS-Servo-Decoders partagent cette interface et cette logique.  
Aucun ordinateur nécessaire. Aucun CV. Câblez simplement, adressez et faites rouler.

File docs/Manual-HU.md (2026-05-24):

> 🌐 &nbsp; [🇬🇧 EN](Manual-EN.md) &nbsp;|&nbsp; [🇩🇪 DE](Manual-DE.md) &nbsp;|&nbsp; [🇫🇷 FR](Manual-FR.md) &nbsp;|&nbsp; [🇳🇱 NL](Manual-NL.md) &nbsp;|&nbsp; [🇪🇸 ES](Manual-ES.md) &nbsp;|&nbsp; [🇮🇹 IT](Manual-IT.md) &nbsp;|&nbsp; [🇵🇱 PL](Manual-PL.md) &nbsp;|&nbsp; [🇨🇿 CS](Manual-CS.md) &nbsp;|&nbsp; [🇩🇰 DA](Manual-DA.md) &nbsp;|&nbsp; [🇳🇴 NO](Manual-NO.md) &nbsp;|&nbsp; [🇸🇪 SV](Manual-SV.md) &nbsp;|&nbsp; 🇭🇺 HU &nbsp;|&nbsp; [🇵🇹 PT](Manual-PT.md)

# OS-Servo-Dekóderek Kézikönyve

## 📘 Bevezetés
Az OS-Servo-Decoder egy egyszerű és megbízható DCC kiegészítő dekóder, amelyet legfeljebb 8 szervómotor meghajtására terveztek. Rugalmas konfigurációs lehetőségekkel, opcionális külső relés modulokkal a polaritásváltáshoz, valamint közvetlen vezérléssel támogatja a modern modellvasutakat — bemeneti kapcsolókon, DCC kiegészítő parancsokon és mozdony funkciógombokon (F1–F8) keresztül egyaránt.

---

## 📚 Tartalomjegyzék

- [OS-Servo-Dekóderek Kézikönyve](#os-servo-dekóderek-kézikönyve)
  - [📘 Bevezetés](#-bevezetés)
  - [📚 Tartalomjegyzék](#-tartalomjegyzék)
  - [🔧 Jellemzők](#-jellemzők)
  - [🔌 A Dekóder Csatlakoztatása](#-a-dekóder-csatlakoztatása)
  - [💪 A Szervó Kimenetek Vezérlése](#-a-szervó-kimenetek-vezérlése)
  - [🛠️ DCC Konfigurációs Mód](#️-dcc-konfigurációs-mód)
  - [🛠️ Gombos Konfigurációs Mód](#️-gombos-konfigurációs-mód)
  - [🌟 Szervópozíciók Tárolása](#-szervópozíciók-tárolása)
  - [🚗 Mozdony Funkció Módok](#-mozdony-funkció-módok)
  - [⚖️ Cím Eltolás](#️-cím-eltolás)
  - [⏰ Automatikus Váltakozó Mód](#-automatikus-váltakozó-mód)
  - [📊 Összefoglalás](#-összefoglalás)

---

## 🔧 Jellemzők
- Legfeljebb 8 szervót vezérel  
- Dugaszolható csavartalpas csatlakozókat használ az egyszerű bekötéshez  
- Külső relés modulok  
- Teljes mértékben támogatja:  
  - Szabványos kitérő mozgást  
  - Polaritásváltást (ahol támogatott)  
  - Állítható szervó végállásokat (gombokon keresztül)  
- Önálló konfiguráció: nincs szükség PC-re, CV-re vagy programozóra  
- Opcionális DCC mozdony funkció vezérlés (F1–F18)  
- Támogatja a Roco 4-es cím eltolást  

---

## 🔌 A Dekóder Csatlakoztatása

OS-Servo-Decoder-8 különböző relébővítő konfigurációkkal

*Az OS-Servo-Decoder-8 különböző bedugott relébővítő modulokkal (bal felső: reteszelő relék; jobb felső: általános célú relék; alul: kombinációk csatlakoztatott szervókkal).*

Az OS-Servo-Decoder-8 ugyanolyan bekötési elrendezést használ, mint az OS-Solenoid-Decoder:

- **Felső csatlakozófej (POW / DCC):** DCC sínfeszültséget vagy DC tápellátást csatlakoztass (max. 19 V)
- ⚠️ **Fontos:** Ne használj AC feszültséget — ez megrongálja a dekódert
- **Szervó csatlakozófejek (jobb oldal):** Csatlakoztass minden szervómotort a 3 tűs csatlakozóhoz
  - Szabványos lábkiosztás: **GND — +5 V — Jel**
- **Relés csatlakozók (bal oldal):** A, COM, B — OS relébővítő modulokhoz

---

## 💪 A Szervó Kimenetek Vezérlése

Minden szervó kimenet egy DCC kiegészítő cím által vezérelt. Amikor a dekóder DCC parancsot kap egy hozzárendelt címre, a szervót simán a tárolt pozícióba mozgatja az adott parancsállapothoz (EGYENES vagy ÍVELT).

- Az **EGYENES** parancs küldése a szervót a tárolt egyenes végállásba mozgatja.
- Az **ÍVELT** parancs küldése a szervót a tárolt ívelt végállásba mozgatja.
- Ha relébővítő modulok vannak felszerelve, a relékontaktusok szinkronban kapcsolnak a szervóval a szárpolarizáláshoz.

A szervó végállások tárolása mozdony funkciógombokon keresztül történik — lásd [Szervópozíciók Tárolása](#-szervópozíciók-tárolása) alább.

---

## 🛠️ DCC Konfigurációs Mód

A dekóder egy olyan konfigurációs módot támogat, amely teljes egészében a DCC szabályozódból működtethető — nincs szükség számítógépre vagy CV programozóra.

A konfigurációs módba lépéshez válaszd ki a **9999** mozdony címet a szabályozódon, és állítsd az **F0, F1 és F2 billentyűket mind KI** állásra. A dekóder belép a konfigurációs módba, és elfogadja a funkciógombok parancsait.

A konfigurációs módban a funkciógombok (F1–F8) segítségével állíts be opciókat az alábbi szakaszokban leírtak szerint. Nyomj **F0 = KI** gombot a kilépéshez és a normál működéshez való visszatéréshez.

---

## 🛠️ Gombos Konfigurációs Mód

A lapon két fizikai gomb található: **KONFIGURÁLÁS** és **VÁLTÁS**.

- **KONFIGURÁLÁS** — közvetlenül belép a konfigurációs módba, szabályozó nélkül. A dekóder LED visszajelzéssel jelzi az aktív beállítást.
- **VÁLTÁS** — manuálisan váltja a jelenleg kiválasztott szervó kimenetet a két tárolt pozíció között. Hasznos a mozgás teszteléséhez és a végállások beállításához.

---

## 🌟 Szervópozíciók Tárolása
Futási módban ezekkel a funkciókkal lehet programozni:

- **F1 = BE ➔** Aktuális pozíció mentése *ÍVELT*-ként  
- **F2 = BE ➔** Aktuális pozíció mentése *EGYENES*-ként  
- **F3 = BE ➔** Szárrelé invertálása *(csak 6 reléses modellen)*  
- **F0 = KI ➔** Kilépés a Futási módból  

---

## 🚗 Mozdony Funkció Módok
Konfigurációs módban a dekóder vezérléséhez kiegészítő parancsok helyett mozdony funkciógombokat is választhatsz.

- **F4 = BE ➔** Mozdony vezérlés letiltása *(alapértelmezett)*  
- **F5 = BE ➔** Mozdony funkcióvezérlés engedélyezése *(F1–F8)* — 1 címet használ  
- **F6 = BE ➔** 4 funkciós mód engedélyezése *(F1–F4)* — 2 címet használ  

Ez ultragyors kapcsolást tesz lehetővé olyan szabályozókkal, mint a Roco Lokmaus vagy Multimaus.

---

## ⚖️ Cím Eltolás
A Roco 4-es eltolásának kompenzálásához használd:

- **F7 = BE ➔** 4-es cím eltolás engedélyezése  

---

## ⏰ Automatikus Váltakozó Mód
Kiválasztott motor automatikus váltakozásának engedélyezése:

- **F8 = BE ➔** A motor minden 5 másodpercben vált  
  - A sebességet a szabályozó vezérli  
  - A szabályozó iránya nem számít  
  - 0-ás sebesség = lassú, Maximum = gyors  

Ebben a módban a motor már nem a szabályozó funkciógombjaihoz van kötve.

---

## 📊 Összefoglalás
- Használd a gombokat a közvetlen beállításhoz és a szervó beállításhoz  
- Használd a DCC mozdony **9999** címet **F0, F1, F2 KI** állással a konfigurációs módba való belépéshez  
- Használd az **F1/F2** gombokat a szervópozíciók tárolásához  
- Használd az **F4–F8** gombokat a mozdony funkcióvezérlés, cím eltolás vagy váltakozó módok engedélyezéséhez  

Minden OS-Servo-Dekóder ezt a felületet és logikát osztja.  
Nincs szükség számítógépre. Nincs CV. Csak bekötni, megszámozni és indítani.

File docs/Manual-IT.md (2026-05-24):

> 🌐 &nbsp; [🇬🇧 EN](Manual-EN.md) &nbsp;|&nbsp; [🇩🇪 DE](Manual-DE.md) &nbsp;|&nbsp; [🇫🇷 FR](Manual-FR.md) &nbsp;|&nbsp; [🇳🇱 NL](Manual-NL.md) &nbsp;|&nbsp; [🇪🇸 ES](Manual-ES.md) &nbsp;|&nbsp; 🇮🇹 IT &nbsp;|&nbsp; [🇵🇱 PL](Manual-PL.md) &nbsp;|&nbsp; [🇨🇿 CS](Manual-CS.md) &nbsp;|&nbsp; [🇩🇰 DA](Manual-DA.md) &nbsp;|&nbsp; [🇳🇴 NO](Manual-NO.md) &nbsp;|&nbsp; [🇸🇪 SV](Manual-SV.md) &nbsp;|&nbsp; [🇭🇺 HU](Manual-HU.md) &nbsp;|&nbsp; [🇵🇹 PT](Manual-PT.md)

# Manuale OS-Servo-Decoder-8

## 📘 Introduzione
L'OS-Servo-Decoder è un decoder DCC per accessori semplice e robusto progettato per pilotare fino a 8 servomotori. Supporta i moderni plastici ferroviari digitali con opzioni di configurazione flessibili, moduli relè esterni per la commutazione della polarità (opzionali) e controllo diretto tramite interruttori di ingresso, comandi DCC per accessori e funzioni locomotiva (F1–F8).

---

## 📚 Indice

- [Manuale OS-Servo-Decoder-8](#manuale-os-servo-decoder-8)
  - [📘 Introduzione](#-introduzione)
  - [📚 Indice](#-indice)
  - [🔧 Caratteristiche](#-caratteristiche)
  - [🔌 Collegamento del Decoder](#-collegamento-del-decoder)
  - [💪 Controllo delle Uscite Servo](#-controllo-delle-uscite-servo)
  - [🛠️ Modalità di Configurazione DCC](#️-modalità-di-configurazione-dcc)
  - [🛠️ Modalità di Configurazione tramite Pulsante](#️-modalità-di-configurazione-tramite-pulsante)
  - [🌟 Memorizzazione delle Posizioni Servo](#-memorizzazione-delle-posizioni-servo)
  - [🚗 Modalità Funzioni Locomotiva](#-modalità-funzioni-locomotiva)
  - [⚖️ Offset Indirizzo](#️-offset-indirizzo)
  - [⏰ Modalità Commutazione Automatica](#-modalità-commutazione-automatica)
  - [📊 Riepilogo](#-riepilogo)

---

## 🔧 Caratteristiche
- Controlla fino a 8 servo  
- Utilizza morsetti a vite innestabili per un cablaggio semplice  
- Moduli relè esterni  
- Supporto completo per:  
  - Movimento standard degli scambi  
  - Commutazione della polarità (dove supportato)  
  - Posizioni finali del servo regolabili (tramite pulsanti)  
- Configurazione autonoma: non richiede PC, CV o programmatori  
- Controllo opzionale tramite funzioni locomotiva DCC (F1–F18)  
- Supporto offset a 4 indirizzi Roco  

---

## 🔌 Collegamento del Decoder

OS-Servo-Decoder-8 con diverse configurazioni di estensione relè

*L'OS-Servo-Decoder-8 mostrato con vari moduli relè di estensione inseriti (in alto a sinistra: relè a mantenimento; in alto a destra: relè a uso generale; in basso: combinazioni con servo collegati).*

L'OS-Servo-Decoder-8 utilizza lo stesso schema di cablaggio dell'OS-Solenoid-Decoder:

- **Connettore superiore (POW / DCC):** collegare la tensione del binario DCC oppure un'alimentazione DC (max 19 V)
- ⚠️ **Importante:** non utilizzare tensione AC — danneggerà il decoder
- **Connettori servo (lato destro):** collegare ciascun servomotore al connettore a 3 pin
  - Pinout standard: **GND — +5 V — Segnale**
- **Connettori relè (lato sinistro):** A, COM, B — per i moduli di estensione OS-relays

---

## 💪 Controllo delle Uscite Servo

Ogni uscita servo è controllata da un indirizzo DCC per accessori. Quando il decoder riceve un comando DCC per un indirizzo assegnato, sposta il servo in modo fluido verso la posizione memorizzata per quello stato di comando (DRITTO o CURVO).

- L'invio del comando **DRITTO** sposta il servo alla posizione finale dritta memorizzata.
- L'invio del comando **CURVO** sposta il servo alla posizione finale curva memorizzata.
- Se sono montati moduli relè di estensione, i contatti del relè commutano in sincronia con il servo per la polarizzazione del frog.

Le posizioni finali del servo vengono memorizzate utilizzando i tasti funzione della locomotiva — vedere [Memorizzazione delle Posizioni Servo](#-memorizzazione-delle-posizioni-servo) di seguito.

---

## 🛠️ Modalità di Configurazione DCC

Il decoder supporta una modalità di configurazione che funziona interamente dal proprio regolatore DCC — senza computer, senza programmatore CV.

Per accedere alla modalità di configurazione, selezionare l'indirizzo locomotiva **9999** sul proprio regolatore e impostare **F0, F1 e F2 tutti su OFF**. Il decoder entrerà in modalità configurazione e accetterà i comandi dei tasti funzione.

Una volta in modalità configurazione, utilizzare i tasti funzione (F1–F8) per impostare le opzioni come descritto nelle sezioni seguenti. Premere **F0 = OFF** per uscire e tornare al funzionamento normale.

---

## 🛠️ Modalità di Configurazione tramite Pulsante

La scheda dispone di due pulsanti fisici: **CONFIGURE** e **TOGGLE**.

- **CONFIGURE** — accede direttamente alla modalità di configurazione, senza necessità di un regolatore. Il decoder risponde con segnalazione LED che indica l'impostazione attiva.
- **TOGGLE** — commuta manualmente l'uscita servo selezionata tra le due posizioni memorizzate. Utile per testare il movimento e regolare le posizioni finali.

---

## 🌟 Memorizzazione delle Posizioni Servo
In modalità di esecuzione, utilizzare queste funzioni per programmare:

- **F1 = ON ➔** Salva la posizione attuale come *CURVO*  
- **F2 = ON ➔** Salva la posizione attuale come *DRITTO*  
- **F3 = ON ➔** Inverti il relè frog *(solo modello a 6 relè)*  
- **F0 = OFF ➔** Esci dalla modalità di esecuzione  

---

## 🚗 Modalità Funzioni Locomotiva
In modalità configurazione, è possibile scegliere di controllare il decoder tramite i tasti funzione locomotiva anziché i comandi per accessori.

- **F4 = ON ➔** Disabilita il controllo locomotiva *(predefinito)*  
- **F5 = ON ➔** Abilita la modalità funzione locomotiva *(F1–F8)* — utilizza 1 indirizzo  
- **F6 = ON ➔** Abilita la modalità a 4 funzioni *(F1–F4)* — utilizza 2 indirizzi  

Ciò consente una commutazione ultrarapida con regolatori come Roco Lokmaus o Multimaus.

---

## ⚖️ Offset Indirizzo
Per compensare l'offset di 4 di Roco, utilizzare:

- **F7 = ON ➔** Abilita l'offset a 4 indirizzi  

---

## ⏰ Modalità Commutazione Automatica
Abilitare la commutazione automatica di un motore selezionato:

- **F8 = ON ➔** Il motore commuta ogni 5 secondi  
  - La velocità è controllata dal regolatore  
  - La direzione del regolatore non ha importanza  
  - Regolatore a 0 = lento, Massimo = veloce  

In questa modalità, il motore non è più subordinato ai tasti funzione del regolatore.

---

## 📊 Riepilogo
- Utilizzare i pulsanti per la configurazione diretta e la regolazione del servo  
- Utilizzare l'indirizzo locomotiva DCC **9999** con **F0, F1, F2 OFF** per accedere alla modalità configurazione  
- Utilizzare **F1/F2** per memorizzare le posizioni del servo  
- Utilizzare **F4–F8** per abilitare il controllo tramite funzioni locomotiva, l'offset dell'indirizzo o le modalità di commutazione  

Tutti gli OS-Servo-Decoder condividono questa interfaccia e logica.  
Nessun computer necessario. Nessun CV. Basta cablarlo, impostare l'indirizzo e farlo funzionare.

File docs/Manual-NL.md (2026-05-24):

> 🌐 &nbsp; [🇬🇧 EN](Manual-EN.md) &nbsp;|&nbsp; [🇩🇪 DE](Manual-DE.md) &nbsp;|&nbsp; [🇫🇷 FR](Manual-FR.md) &nbsp;|&nbsp; 🇳🇱 NL &nbsp;|&nbsp; [🇪🇸 ES](Manual-ES.md) &nbsp;|&nbsp; [🇮🇹 IT](Manual-IT.md) &nbsp;|&nbsp; [🇵🇱 PL](Manual-PL.md) &nbsp;|&nbsp; [🇨🇿 CS](Manual-CS.md) &nbsp;|&nbsp; [🇩🇰 DA](Manual-DA.md) &nbsp;|&nbsp; [🇳🇴 NO](Manual-NO.md) &nbsp;|&nbsp; [🇸🇪 SV](Manual-SV.md) &nbsp;|&nbsp; [🇭🇺 HU](Manual-HU.md) &nbsp;|&nbsp; [🇵🇹 PT](Manual-PT.md)

# OS-Servo-Decoders Handleiding

## 📘 Inleiding
De OS-Servo-Decoder is een eenvoudige en robuuste DCC-accessoire­decoder ontworpen voor het aansturen van maximaal 8 servo­motoren. Hij ondersteunt moderne modelbanen met flexibele configuratie­opties, externe relais­modules voor polariteits­schakeling (optioneel) en directe besturing via invoer­schakelaars, DCC-accessoire­commando's en locomotief­functies (F1–F8).

---

## 📚 Inhoudsopgave

- [OS-Servo-Decoders Handleiding](#os-servo-decoders-handleiding)
  - [📘 Inleiding](#-inleiding)
  - [📚 Inhoudsopgave](#-inhoudsopgave)
  - [🔧 Kenmerken](#-kenmerken)
  - [🔌 De decoder aansluiten](#-de-decoder-aansluiten)
  - [💪 De servo­uitgangen bedienen](#-de-servo­uitgangen-bedienen)
  - [🛠️ DCC-configuratie­modus](#️-dcc-configuratiemodus)
  - [🛠️ Knop­configuratie­modus](#️-knopconfiguratiemodus)
  - [🌟 Servo­posities opslaan](#-servopo­sities-opslaan)
  - [🚗 Locomotief­functie­modi](#-locomotieffunctiemodi)
  - [⚖️ Adres­offset](#️-adresoffset)
  - [⏰ Auto-wissel­modus](#-auto-wisselmodus)
  - [📊 Samenvatting](#-samenvatting)

---

## 🔧 Kenmerken
- Bestuurt tot 8 servo's  
- Gebruikt insteekbare schroef­klemmen voor eenvoudige bedrading  
- Externe relais­modules  
- Volledig ondersteunt:  
  - Standaard wissel­beweging  
  - Polariteits­schakeling (waar ondersteund)  
  - Instelbare servo­eindstanden (via knoppen)  
- Zelfstandige configuratie: geen pc, CV's of programmeurs vereist  
- Optionele DCC-locomotief­functiebe­sturing (F1–F18)  
- Ondersteunt Roco 4-adres­offset  

---

## 🔌 De decoder aansluiten

OS-Servo-Decoder-8 met verschillende relais­uitbreidings­configuraties

*De OS-Servo-Decoder-8 getoond met diverse relais­uitbreidings­modules aangesloten (linksboven: zelfhoudende relais; rechtsboven: algemeen­gebruik­relais; onder: combinaties met aangesloten servo's).*

De OS-Servo-Decoder-8 gebruikt dezelfde bedradingsindeling als de OS-Solenoid-Decoder:

- **Bovenste header (POW / DCC):** Sluit DCC-baan­spanning of een DC-voeding aan (max. 19 V)
- ⚠️ **Belangrijk:** Gebruik geen AC-spanning — dit beschadigt de decoder
- **Servo-headers (rechterzijde):** Sluit elke servo­motor aan op de 3-polige aansluiting
  - Standaard pin­indeling: **GND — +5 V — Signaal**
- **Relais­aansluitingen (linkerzijde):** A, COM, B — voor OS-relais­uitbreidings­modules

---

## 💪 De servo­uitgangen bedienen

Elke servo­uitgang wordt bestuurd door een DCC-accessoire­adres. Wanneer de decoder een DCC-commando ontvangt voor een toegewezen adres, beweegt de servo soepel naar de opgeslagen positie voor die commando­staat (RECHT of GEBOGEN).

- Het **RECHT**-commando beweegt de servo naar de opgeslagen rechte eindstand.
- Het **GEBOGEN**-commando beweegt de servo naar de opgeslagen gebogen eindstand.
- Als relais­uitbreidings­modules zijn geplaatst, schakelen de relais­contacten gelijktijdig met de servo voor hartpunt­polarisering.

Servo­eindstanden worden opgeslagen met locomotief­functie­toetsen — zie [Servo­posities opslaan](#-servopo­sities-opslaan) hieronder.

---

## 🛠️ DCC-configuratie­modus

De decoder ondersteunt een configuratie­modus die volledig werkt via uw DCC-handregelaar — geen computer, geen CV-programmeur vereist.

Om de configuratie­modus te activeren, selecteert u locomotief­adres **9999** op uw handregelaar en zet u **F0, F1 en F2 alle op UIT**. De decoder gaat de configuratie­modus in en accepteert functie­toets­commando's.

Eenmaal in de configuratie­modus, gebruikt u de functie­toetsen (F1–F8) om opties in te stellen zoals beschreven in de onderstaande secties. Druk op **F0 = UIT** om af te sluiten en terug te keren naar normale werking.

---

## 🛠️ Knop­configuratie­modus

De kaart heeft twee fysieke knoppen: **CONFIGURE** en **TOGGLE**.

- **CONFIGURE** — activeert de configuratie­modus direct, zonder een handregelaar. De decoder reageert met LED-feedback die de actieve instelling aangeeft.
- **TOGGLE** — schakelt de momenteel geselecteerde servo­uitgang handmatig tussen de twee opgeslagen standen. Handig voor het testen van beweging en het aanpassen van eindstanden.

---

## 🌟 Servo­posities opslaan
Gebruik in de rijmodus deze functies om te programmeren:

- **F1 = AAN ➔** Sla huidige positie op als *GEBOGEN*  
- **F2 = AAN ➔** Sla huidige positie op als *RECHT*  
- **F3 = AAN ➔** Keer hartpunt­relais om *(alleen 6-relais model)*  
- **F0 = UIT ➔** Verlaat rijmodus  

---

## 🚗 Locomotief­functie­modi
In de configuratie­modus kunt u kiezen om de decoder te bedienen via locomotief­functie­toetsen in plaats van accessoire­commando's.

- **F4 = AAN ➔** Locomotief­besturing uitschakelen *(standaard)*  
- **F5 = AAN ➔** Locomotief­functiemodus inschakelen *(F1–F8)* — gebruikt 1 adres  
- **F6 = AAN ➔** 4-functiemodus inschakelen *(F1–F4)* — gebruikt 2 adressen  

Dit maakt ultra­snel schakelen mogelijk via handregelaars zoals de Roco Lokmaus of Multimaus.

---

## ⚖️ Adres­offset
Om te compenseren voor de offset van 4 bij Roco, gebruik:

- **F7 = AAN ➔** 4-adres­offset inschakelen  

---

## ⏰ Auto-wissel­modus
Schakel automatisch wisselen van een geselecteerde motor in:

- **F8 = AAN ➔** Motor wisselt elke 5 seconden  
  - Snelheid wordt bepaald door de rijregelaar  
  - Rijrichting doet er niet toe  
  - Rijregelaar 0 = langzaam, Max = snel  

In deze modus is de motor niet langer gekoppeld aan de functie­toetsen van de rijregelaar.

---

## 📊 Samenvatting
- Gebruik de knoppen voor directe instelling en servo­aanpassing  
- Gebruik DCC-locomotief­adres **9999** met **F0, F1, F2 UIT** om de configuratie­modus te activeren  
- Gebruik **F1/F2** om servo­posities op te slaan  
- Gebruik **F4–F8** om locomotief­functiebe­sturing, adres­offset of wissel­modi in te schakelen  

Alle OS-Servo-Decoders delen deze interface en logica.  
Geen computer nodig. Geen CV's. Gewoon bedraden, adresseren en rijden.

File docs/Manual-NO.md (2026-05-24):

> 🌐 &nbsp; [🇬🇧 EN](Manual-EN.md) &nbsp;|&nbsp; [🇩🇪 DE](Manual-DE.md) &nbsp;|&nbsp; [🇫🇷 FR](Manual-FR.md) &nbsp;|&nbsp; [🇳🇱 NL](Manual-NL.md) &nbsp;|&nbsp; [🇪🇸 ES](Manual-ES.md) &nbsp;|&nbsp; [🇮🇹 IT](Manual-IT.md) &nbsp;|&nbsp; [🇵🇱 PL](Manual-PL.md) &nbsp;|&nbsp; [🇨🇿 CS](Manual-CS.md) &nbsp;|&nbsp; [🇩🇰 DA](Manual-DA.md) &nbsp;|&nbsp; 🇳🇴 NO &nbsp;|&nbsp; [🇸🇪 SV](Manual-SV.md) &nbsp;|&nbsp; [🇭🇺 HU](Manual-HU.md) &nbsp;|&nbsp; [🇵🇹 PT](Manual-PT.md)

# OS-Servo-Decoders Manual

## 📘 Innledning
OS-Servo-Decoder er en enkel og robust DCC-tilbehørsdekoder utviklet for å drive opptil 8 servomotorer. Den støtter moderne modelljernbaner med fleksible konfigurasjonsalternativer, eksterne relé-moduler for polaritetskobling (valgfritt) og direkte styring ved hjelp av både inngangsbrytere, DCC-tilbehørskommandoer og lokomotivfunksjoner (F1–F8).

---

## 📚 Innholdsfortegnelse

- [OS-Servo-Decoders Manual](#os-servo-decoders-manual)
  - [📘 Innledning](#-innledning)
  - [📚 Innholdsfortegnelse](#-innholdsfortegnelse)
  - [🔧 Egenskaper](#-egenskaper)
  - [🔌 Tilkobling av dekoderen](#-tilkobling-av-dekoderen)
  - [💪 Styring av servoutgangene](#-styring-av-servoutgangene)
  - [🛠️ DCC-konfigurasjonsmodus](#️-dcc-konfigurasjonsmodus)
  - [🛠️ Knapp-konfigurasjonsmodus](#️-knapp-konfigurasjonsmodus)
  - [🌟 Lagre servoposisjoner](#-lagre-servoposisjoner)
  - [🚗 Lokomotivfunksjonsmodus](#-lokomotivfunksjonsmodus)
  - [⚖️ Adresseforskyvning](#️-adresseforskyvning)
  - [⏰ Auto-veksel-modus](#-auto-veksel-modus)
  - [📊 Sammendrag](#-sammendrag)

---

## 🔧 Egenskaper
- Styrer opptil 8 servoer  
- Bruker uttrekkbare skrueterminaler for enkel kabling  
- Eksterne relé-moduler  
- Støtter fullt ut:  
  - Standard sporskiftebevegelse  
  - Polaritetskobling (der støttet)  
  - Justerbare servo-endeposisjoner (via knapper)  
- Frittstående konfigurasjon: ingen PC, CV-er eller programmerere nødvendig  
- Valgfri DCC-lokomotivfunksjonsstyring (F1–F18)  
- Støtter Roco 4-adresseforskyvning  

---

## 🔌 Tilkobling av dekoderen

OS-Servo-Decoder-8 med ulike relé-utvidelseskonfigurasjoner

*OS-Servo-Decoder-8 vist med ulike relé-utvidelsesmoduler plugget inn (øverst til venstre: selvholdende reléer; øverst til høyre: generelle reléer; nederst: kombinasjoner med servoer tilkoblet).*

OS-Servo-Decoder-8 bruker samme kablingslayout som OS-Solenoid-Decoder:

- **Toppoverskrift (POW / DCC):** Koble enten DCC sporsspenning eller en DC-strømforsyning (maks 19 V)
- ⚠️ **Viktig:** Ikke bruk AC-spenning — dette vil skade dekoderen
- **Servo-overskrifter (høyre side):** Koble hver servomotor til 3-pins koblingen
  - Standard pinout: **GND — +5 V — Signal**
- **Relé-koblinger (venstre side):** A, COM, B — for OS relé-utvidelsesmoduler

---

## 💪 Styring av servoutgangene

Hver servoutgang styres av en DCC-tilbehørsadresse. Når dekoderen mottar en DCC-kommando for en tildelt adresse, beveger den servoen jevnt til den lagrede posisjonen for den kommandotilstanden (RETT eller KURVET).

- Sending av **RETT**-kommandoen beveger servoen til den lagrede rette endeposisjonen.
- Sending av **KURVET**-kommandoen beveger servoen til den lagrede kurvede endeposisjonen.
- Hvis relé-utvidelsesmoduler er montert, kobles reléekontaktene synkront med servoen for frog-polarisering.

Servo-endeposisjoner lagres ved hjelp av lokomotivfunksjonstaster — se [Lagre servoposisjoner](#-lagre-servoposisjoner) nedenfor.

---

## 🛠️ DCC-konfigurasjonsmodus

Dekoderen støtter en konfigurasjonsmodus som fungerer helt fra DCC-reguleringen din — ingen datamaskin, ingen CV-programmerer nødvendig.

For å gå inn i konfigurasjonsmodus, velg lokoadresse **9999** på regulatoren din og sett **F0, F1 og F2 alle til AV**. Dekoderen vil gå inn i konfig-modus og akseptere funksjonstastkommandoer.

Når du er i konfig-modus, bruk funksjonstastene (F1–F8) til å angi alternativer som beskrevet i avsnittene nedenfor. Trykk **F0 = AV** for å avslutte og gå tilbake til normal drift.

---

## 🛠️ Knapp-konfigurasjonsmodus

Kortet har to fysiske knapper: **CONFIGURE** og **TOGGLE**.

- **CONFIGURE** — går direkte inn i konfigurasjonsmodus, uten behov for en regulator. Dekoderen responderer med LED-tilbakemelding som indikerer den aktive innstillingen.
- **TOGGLE** — veksler manuelt den valgte servoutgangen mellom de to lagrede posisjonene. Nyttig for å teste bevegelse og justere endeposisjoner.

---

## 🌟 Lagre servoposisjoner
Mens i Kjøremodus, bruk disse funksjonene for å programmere:

- **F1 = PÅ ➔** Lagre gjeldende posisjon som *KURVET*  
- **F2 = PÅ ➔** Lagre gjeldende posisjon som *RETT*  
- **F3 = PÅ ➔** Inverter frog-relé *(kun 6-relé-modell)*  
- **F0 = AV ➔** Avslutt kjøremodus  

---

## 🚗 Lokomotivfunksjonsmodus
I konfig-modus kan du velge å styre dekoderen ved hjelp av lokomotivfunksjonstaster i stedet for tilbehørskommandoer.

- **F4 = PÅ ➔** Deaktiver loko-styring *(standard)*  
- **F5 = PÅ ➔** Aktiver lokomotivfunksjonsmodus *(F1–F8)* — bruker 1 adresse  
- **F6 = PÅ ➔** Aktiver 4-funksjonsmodus *(F1–F4)* — bruker 2 adresser  

Dette gir ultrarask kobling ved hjelp av regulatorer som Roco Lokmaus eller Multimaus.

---

## ⚖️ Adresseforskyvning
For å kompensere for Roco sin forskyvning på 4, bruk:

- **F7 = PÅ ➔** Aktiver 4-adresseforskyvning  

---

## ⏰ Auto-veksel-modus
Aktiver automatisk veksling av valgt motor:

- **F8 = PÅ ➔** Motor veksler hvert 5. sekund  
  - Hastigheten styres av regulatoren  
  - Regulatorretningen spiller ingen rolle  
  - Regulator 0 = sakte, Maks = raskt  

I denne modusen er motoren ikke lenger styrt av regulatorens funksjonstaster.

---

## 📊 Sammendrag
- Bruk knappene for direkte oppsett og servijustering  
- Bruk DCC lokoadresse **9999** med **F0, F1, F2 AV** for å gå inn i konfig-modus  
- Bruk **F1/F2** til å lagre servoposisjoner  
- Bruk **F4–F8** for å aktivere lokomotivfunksjonsstyring, adresseforskyvning eller vekselmodus  

Alle OS-Servo-Decoders deler dette grensesnittet og denne logikken.  
Ingen datamaskin nødvendig. Ingen CV-er. Bare koble til, angi adresse og kjør.

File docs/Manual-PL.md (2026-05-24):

> 🌐 &nbsp; [🇬🇧 EN](Manual-EN.md) &nbsp;|&nbsp; [🇩🇪 DE](Manual-DE.md) &nbsp;|&nbsp; [🇫🇷 FR](Manual-FR.md) &nbsp;|&nbsp; [🇳🇱 NL](Manual-NL.md) &nbsp;|&nbsp; [🇪🇸 ES](Manual-ES.md) &nbsp;|&nbsp; [🇮🇹 IT](Manual-IT.md) &nbsp;|&nbsp; 🇵🇱 PL &nbsp;|&nbsp; [🇨🇿 CS](Manual-CS.md) &nbsp;|&nbsp; [🇩🇰 DA](Manual-DA.md) &nbsp;|&nbsp; [🇳🇴 NO](Manual-NO.md) &nbsp;|&nbsp; [🇸🇪 SV](Manual-SV.md) &nbsp;|&nbsp; [🇭🇺 HU](Manual-HU.md) &nbsp;|&nbsp; [🇵🇹 PT](Manual-PT.md)

# Instrukcja dekoderów OS-Servo

## 📘 Wprowadzenie
OS-Servo-Decoder to prosty i niezawodny dekoder akcesoriów DCC zaprojektowany do sterowania nawet 8 serwomechanizmami. Obsługuje nowoczesne makiety kolejowe z elastycznymi opcjami konfiguracji, zewnętrznymi modułami przekaźnikowymi do przełączania biegunowości (opcjonalnie) oraz bezpośrednim sterowaniem za pomocą przełączników wejściowych, poleceń akcesoriów DCC i funkcji lokomotywy (F1–F8).

---

## 📚 Spis treści

- [Instrukcja dekoderów OS-Servo](#instrukcja-dekoderów-os-servo)
  - [📘 Wprowadzenie](#-wprowadzenie)
  - [📚 Spis treści](#-spis-treści)
  - [🔧 Właściwości](#-właściwości)
  - [🔌 Podłączenie dekodera](#-podłączenie-dekodera)
  - [💪 Sterowanie wyjściami serw](#-sterowanie-wyjściami-serw)
  - [🛠️ Tryb konfiguracji DCC](#️-tryb-konfiguracji-dcc)
  - [🛠️ Tryb konfiguracji przyciskami](#️-tryb-konfiguracji-przyciskami)
  - [🌟 Zapisywanie pozycji serw](#-zapisywanie-pozycji-serw)
  - [🚗 Tryby funkcji lokomotywy](#-tryby-funkcji-lokomotywy)
  - [⚖️ Przesunięcie adresu](#️-przesunięcie-adresu)
  - [⏰ Tryb automatycznego przełączania](#-tryb-automatycznego-przełączania)
  - [📊 Podsumowanie](#-podsumowanie)

---

## 🔧 Właściwości
- Steruje nawet 8 serwomechanizmami  
- Używa wtykowych zacisków śrubowych do łatwego okablowania  
- Zewnętrzne moduły przekaźnikowe  
- W pełni obsługuje:  
  - Standardowy ruch zwrotnicy  
  - Przełączanie biegunowości (gdzie jest obsługiwane)  
  - Regulowane pozycje końcowe serw (za pomocą przycisków)  
- Autonomiczna konfiguracja: nie wymaga PC, CV ani programatorów  
- Opcjonalne sterowanie funkcjami lokomotywy DCC (F1–F18)  
- Obsługuje przesunięcie 4-adresowe Roco  

---

## 🔌 Podłączenie dekodera

OS-Servo-Decoder-8 z różnymi konfiguracjami rozszerzenia przekaźnikowego

*OS-Servo-Decoder-8 pokazany z różnymi modułami rozszerzenia przekaźnikowego (lewy górny: przekaźniki zatrzaskowe; prawy górny: przekaźniki ogólnego przeznaczenia; dolny: kombinacje z podłączonymi serwomechanizmami).*

OS-Servo-Decoder-8 używa tego samego schematu okablowania co OS-Solenoid-Decoder:

- **Górny nagłówek (POW / DCC):** Podłącz napięcie torowe DCC lub zasilacz DC (maks. 19 V)
- ⚠️ **Ważne:** Nie używaj napięcia AC — uszkodzi to dekoder
- **Nagłówki serw (prawa strona):** Podłącz każdy serwomechanizm do 3-pinowego złącza
  - Standardowy układ pinów: **GND — +5 V — Sygnał**
- **Złącza przekaźnikowe (lewa strona):** A, COM, B — dla modułów rozszerzenia przekaźnikowego OS

---

## 💪 Sterowanie wyjściami serw

Każde wyjście serwa jest sterowane adresem akcesoriów DCC. Gdy dekoder odbiera polecenie DCC dla przypisanego adresu, płynnie przesuwa serwo do zapisanej pozycji dla danego stanu polecenia (PROSTO lub KRZYWO).

- Polecenie **PROSTO** przesuwa serwo do zapisanej prostej pozycji końcowej.
- Polecenie **KRZYWO** przesuwa serwo do zapisanej krzywej pozycji końcowej.
- Jeśli zamontowane są moduły rozszerzenia przekaźnikowego, styki przekaźnikowe przełączają się synchronicznie z serwomechanizmem w celu polaryzacji sercówki.

Pozycje końcowe serw są zapisywane za pomocą klawiszy funkcji lokomotywy — patrz [Zapisywanie pozycji serw](#-zapisywanie-pozycji-serw) poniżej.

---

## 🛠️ Tryb konfiguracji DCC

Dekoder obsługuje tryb konfiguracji działający całkowicie z regulatora DCC — nie wymaga komputera ani programatora CV.

Aby wejść w tryb konfiguracji, wybierz adres lokomotywy **9999** na regulatorze i ustaw **F0, F1 i F2 na WYŁ**. Dekoder wejdzie w tryb konfiguracji i będzie przyjmował polecenia klawiszy funkcji.

Po wejściu w tryb konfiguracji użyj klawiszy funkcji (F1–F8) do ustawiania opcji opisanych w poniższych sekcjach. Naciśnij **F0 = WYŁ**, aby wyjść i wrócić do normalnej pracy.

---

## 🛠️ Tryb konfiguracji przyciskami

Płytka ma dwa fizyczne przyciski: **CONFIGURE** i **TOGGLE**.

- **CONFIGURE** — wchodzi bezpośrednio w tryb konfiguracji bez potrzeby używania regulatora. Dekoder odpowiada sygnalizacją LED wskazującą aktywne ustawienie.
- **TOGGLE** — ręcznie przełącza aktualnie wybrane wyjście serwa między dwiema zapisanymi pozycjami. Przydatne do testowania ruchu i dostosowywania pozycji końcowych.

---

## 🌟 Zapisywanie pozycji serw
W trybie pracy użyj tych funkcji do programowania:

- **F1 = WŁ ➔** Zapisz bieżącą pozycję jako *KRZYWO*  
- **F2 = WŁ ➔** Zapisz bieżącą pozycję jako *PROSTO*  
- **F3 = WŁ ➔** Odwróć przekaźnik sercówki *(tylko model z 6 przekaźnikami)*  
- **F0 = WYŁ ➔** Wyjdź z trybu pracy  

---

## 🚗 Tryby funkcji lokomotywy
W trybie konfiguracji możesz wybrać sterowanie dekoderem za pomocą klawiszy funkcji lokomotywy zamiast poleceń akcesoriów.

- **F4 = WŁ ➔** Wyłącz sterowanie lokomotywą *(domyślnie)*  
- **F5 = WŁ ➔** Włącz tryb funkcji lokomotywy *(F1–F8)* — używa 1 adresu  
- **F6 = WŁ ➔** Włącz tryb 4-funkcyjny *(F1–F4)* — używa 2 adresów  

Umożliwia to bardzo szybkie przełączanie za pomocą regulatorów takich jak Roco Lokmaus lub Multimaus.

---

## ⚖️ Przesunięcie adresu
Aby skompensować przesunięcie o 4 w Roco, użyj:

- **F7 = WŁ ➔** Włącz przesunięcie o 4 adresy  

---

## ⏰ Tryb automatycznego przełączania
Włącz automatyczne przełączanie wybranego silnika:

- **F8 = WŁ ➔** Silnik przełącza się co 5 sekund  
  - Prędkość jest kontrolowana przez regulator  
  - Kierunek regulatora nie ma znaczenia  
  - Regulator 0 = wolno, Max = szybko  

W tym trybie silnik nie jest już zależny od klawiszy funkcji regulatora.

---

## 📊 Podsumowanie
- Użyj przycisków do bezpośredniej konfiguracji i regulacji serw  
- Użyj adresu lokomotywy DCC **9999** z **F0, F1, F2 WYŁ**, aby wejść w tryb konfiguracji  
- Użyj **F1/F2** do zapisywania pozycji serw  
- Użyj **F4–F8**, aby włączyć sterowanie funkcjami lokomotywy, przesunięcie adresu lub tryby przełączania  

Wszystkie OS-Servo-Decodery mają wspólny interfejs i logikę.  
Nie potrzeba komputera. Żadnych CV. Wystarczy podłączyć, zaadresować i uruchomić.

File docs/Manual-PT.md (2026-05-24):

> 🌐 &nbsp; [🇬🇧 EN](Manual-EN.md) &nbsp;|&nbsp; [🇩🇪 DE](Manual-DE.md) &nbsp;|&nbsp; [🇫🇷 FR](Manual-FR.md) &nbsp;|&nbsp; [🇳🇱 NL](Manual-NL.md) &nbsp;|&nbsp; [🇪🇸 ES](Manual-ES.md) &nbsp;|&nbsp; [🇮🇹 IT](Manual-IT.md) &nbsp;|&nbsp; [🇵🇱 PL](Manual-PL.md) &nbsp;|&nbsp; [🇨🇿 CS](Manual-CS.md) &nbsp;|&nbsp; [🇩🇰 DA](Manual-DA.md) &nbsp;|&nbsp; [🇳🇴 NO](Manual-NO.md) &nbsp;|&nbsp; [🇸🇪 SV](Manual-SV.md) &nbsp;|&nbsp; [🇭🇺 HU](Manual-HU.md) &nbsp;|&nbsp; 🇵🇹 PT

# Manual dos OS-Servo-Decoders

## 📘 Introdução
O OS-Servo-Decoder é um decoder de acessórios DCC simples e robusto concebido para accionar até 8 servomotores. Suporta ferrovias em miniatura modernas com opções de configuração flexíveis, módulos de relé externos para comutação de polaridade (opcional) e controlo directo por interruptores de entrada, comandos de acessório DCC e funções de locomotiva (F1–F8).

---

## 📚 Índice

- [Manual dos OS-Servo-Decoders](#manual-dos-os-servo-decoders)
  - [📘 Introdução](#-introdução)
  - [📚 Índice](#-índice)
  - [🔧 Características](#-características)
  - [🔌 Ligar o Decoder](#-ligar-o-decoder)
  - [💪 Controlar as Saídas de Servo](#-controlar-as-saídas-de-servo)
  - [🛠️ Modo de Configuração DCC](#️-modo-de-configuração-dcc)
  - [🛠️ Modo de Configuração por Botão](#️-modo-de-configuração-por-botão)
  - [🌟 Guardar Posições de Servo](#-guardar-posições-de-servo)
  - [🚗 Modos de Função de Locomotiva](#-modos-de-função-de-locomotiva)
  - [⚖️ Desvio de Endereço](#️-desvio-de-endereço)
  - [⏰ Modo de Comutação Automática](#-modo-de-comutação-automática)
  - [📊 Resumo](#-resumo)

---

## 🔧 Características
- Controla até 8 servos  
- Utiliza bornes de parafuso amovíveis para fácil cablagem  
- Módulos de relé externos  
- Suporta completamente:  
  - Movimento padrão de agulha  
  - Comutação de polaridade (onde suportado)  
  - Posições finais de servo ajustáveis (por botões)  
- Configuração autónoma: sem PC, CV nem programadores necessários  
- Controlo opcional por funções de locomotiva DCC (F1–F18)  
- Suporta desvio de 4 endereços da Roco  

---

## 🔌 Ligar o Decoder

OS-Servo-Decoder-8 com diferentes configurações de extensão de relé

*O OS-Servo-Decoder-8 mostrado com vários módulos de extensão de relé ligados (em cima à esquerda: relés de retenção; em cima à direita: relés de uso geral; em baixo: combinações com servos ligados).*

O OS-Servo-Decoder-8 utiliza o mesmo esquema de cablagem que o OS-Solenoid-Decoder:

- **Header superior (POW / DCC):** Ligue tensão de via DCC ou uma fonte de alimentação DC (máx. 19 V)
- ⚠️ **Importante:** Não utilize tensão AC — isto danificará o decoder
- **Headers de servo (lado direito):** Ligue cada servomotor ao conector de 3 pinos
  - Pinagem padrão: **GND — +5 V — Sinal**
- **Conectores de relé (lado esquerdo):** A, COM, B — para módulos de extensão de relé OS

---

## 💪 Controlar as Saídas de Servo

Cada saída de servo é controlada por um endereço de acessório DCC. Quando o decoder recebe um comando DCC para um endereço atribuído, move o servo suavemente para a posição guardada para esse estado de comando (DIRECTO ou CURVO).

- O comando **DIRECTO** move o servo para a sua posição final de direito guardada.
- O comando **CURVO** move o servo para a sua posição final de curvo guardada.
- Se estiverem instalados módulos de extensão de relé, os contactos do relé comutam em sincronia com o servo para a polarização de frog.

As posições finais do servo são guardadas usando teclas de função de locomotiva — consulte [Guardar Posições de Servo](#-guardar-posições-de-servo) abaixo.

---

## 🛠️ Modo de Configuração DCC

O decoder suporta um modo de configuração que funciona inteiramente a partir do seu manípulo DCC — sem computador, sem programador de CV.

Para entrar no modo de configuração, seleccione o endereço de locomotiva **9999** no seu manípulo e coloque **F0, F1 e F2 todas a OFF**. O decoder entra no modo de configuração e aceita comandos de teclas de função.

Estando no modo de configuração, use as teclas de função (F1–F8) para definir opções conforme descrito nas secções abaixo. Prima **F0 = OFF** para sair e regressar ao funcionamento normal.

---

## 🛠️ Modo de Configuração por Botão

A placa tem dois botões físicos: **CONFIGURE** e **TOGGLE**.

- **CONFIGURE** — entra no modo de configuração directamente, sem necessidade de um manípulo. O decoder responde com indicação LED indicando a configuração activa.
- **TOGGLE** — comuta manualmente a saída de servo actualmente seleccionada entre as suas duas posições guardadas. Útil para testar o movimento e ajustar as posições finais.

---

## 🌟 Guardar Posições de Servo
No Modo de Execução, utilize estas funções para programar:

- **F1 = ON ➔** Guardar posição actual como *CURVO*  
- **F2 = ON ➔** Guardar posição actual como *DIRECTO*  
- **F3 = ON ➔** Inverter relé de frog *(apenas no modelo de 6 relés)*  
- **F0 = OFF ➔** Sair do Modo de Execução  

---

## 🚗 Modos de Função de Locomotiva
No Modo de Configuração, pode escolher controlar o decoder usando teclas de função de locomotiva em vez de comandos de acessório.

- **F4 = ON ➔** Desactivar controlo por locomotiva *(predefinição)*  
- **F5 = ON ➔** Activar modo de função de locomotiva *(F1–F8)* — usa 1 endereço  
- **F6 = ON ➔** Activar modo de 4 funções *(F1–F4)* — usa 2 endereços  

Isto permite uma comutação ultra-rápida com manípulos como o Roco Lokmaus ou Multimaus.

---

## ⚖️ Desvio de Endereço
Para compensar o desvio de 4 endereços da Roco, utilize:

- **F7 = ON ➔** Activar desvio de 4 endereços  

---

## ⏰ Modo de Comutação Automática
Activar a comutação automática de um motor seleccionado:

- **F8 = ON ➔** O motor comuta de 5 em 5 segundos  
  - A velocidade é controlada pelo manípulo  
  - A direcção do manípulo não interessa  
  - Manípulo 0 = lento, Máximo = rápido  

Neste modo, o motor deixa de estar subordinado às teclas de função do manípulo.

---

## 📊 Resumo
- Use os botões para configuração directa e ajuste do servo  
- Use o endereço de locomotiva DCC **9999** com **F0, F1, F2 OFF** para entrar no modo de configuração  
- Use **F1/F2** para guardar posições de servo  
- Use **F4–F8** para activar o controlo por função de locomotiva, o desvio de endereço ou os modos de comutação  

Todos os OS-Servo-Decoders partilham esta interface e lógica.  
Sem computador. Sem CVs. Basta ligar, endereçar e utilizar.

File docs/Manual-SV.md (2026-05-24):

> 🌐 &nbsp; [🇬🇧 EN](Manual-EN.md) &nbsp;|&nbsp; [🇩🇪 DE](Manual-DE.md) &nbsp;|&nbsp; [🇫🇷 FR](Manual-FR.md) &nbsp;|&nbsp; [🇳🇱 NL](Manual-NL.md) &nbsp;|&nbsp; [🇪🇸 ES](Manual-ES.md) &nbsp;|&nbsp; [🇮🇹 IT](Manual-IT.md) &nbsp;|&nbsp; [🇵🇱 PL](Manual-PL.md) &nbsp;|&nbsp; [🇨🇿 CS](Manual-CS.md) &nbsp;|&nbsp; [🇩🇰 DA](Manual-DA.md) &nbsp;|&nbsp; [🇳🇴 NO](Manual-NO.md) &nbsp;|&nbsp; 🇸🇪 SV &nbsp;|&nbsp; [🇭🇺 HU](Manual-HU.md) &nbsp;|&nbsp; [🇵🇹 PT](Manual-PT.md)

# OS-Servo-Decoders Manual

## 📘 Introduktion
OS-Servo-Decoder är en enkel och robust DCC-tillbehörsdecoder utformad för att driva upp till 8 servomotorer. Den stöder moderna modellbanor med flexibla konfigurationsalternativ, externa relämoduler för polaritetsväxling (valfritt) och direktstyrning med både ingångsknappar, DCC-tillbehörskommandon och lokfunktioner (F1–F8).

---

## 📚 Innehållsförteckning

- [OS-Servo-Decoders Manual](#os-servo-decoders-manual)
  - [📘 Introduktion](#-introduktion)
  - [📚 Innehållsförteckning](#-innehållsförteckning)
  - [🔧 Funktioner](#-funktioner)
  - [🔌 Ansluta decodern](#-ansluta-decodern)
  - [💪 Styra servoutgångarna](#-styra-servoutgångarna)
  - [🛠️ DCC-konfigurationsläge](#️-dcc-konfigurationsläge)
  - [🛠️ Knapprationsläge](#️-knappkonfigurationsläge)
  - [🌟 Lagra servopositioner](#-lagra-servopositioner)
  - [🚗 Lokfunktionslägen](#-lokfunktionslägen)
  - [⚖️ Adressoffset](#️-adressoffset)
  - [⏰ Auto-växlingsläge](#-auto-växlingsläge)
  - [📊 Sammanfattning](#-sammanfattning)

---

## 🔧 Funktioner
- Styr upp till 8 servon  
- Använder inkopplingsbara skruvplintrar för enkel kabelanslutning  
- Externa relämoduler  
- Fullt stöd för:  
  - Standard växelrörelse  
  - Polaritetsväxling (där det stöds)  
  - Justerbara servoändpositioner (via knappar)  
- Fristående konfiguration: ingen PC, inga CV:er eller programmerare krävs  
- Valfri DCC lokfunktionsstyrning (F1–F18)  
- Stöder Roco 4-adressoffset  

---

## 🔌 Ansluta decodern

OS-Servo-Decoder-8 med olika reläutvidgningskonfigurationer

*OS-Servo-Decoder-8 visad med olika reläutvidgningsmoduler inkopplade (övre vänster: låsande reläer; övre höger: generella reläer; nedre: kombinationer med servon anslutna).*

OS-Servo-Decoder-8 använder samma kopplingsschema som OS-Solenoid-Decoder:

- **Övre kontaktsockel (POW / DCC):** Anslut antingen DCC-spårspänning eller en DC-strömförsörjning (max 19 V)
- ⚠️ **Viktigt:** Använd inte AC-spänning — det skadar decodern
- **Servokontaktsocklarna (höger sida):** Anslut varje servomotor till 3-stiftskontakten
  - Standard stiftkonfiguration: **GND — +5 V — Signal**
- **Reläkontakter (vänster sida):** A, COM, B — för OS reläutvidgningsmoduler

---

## 💪 Styra servoutgångarna

Varje servoutgång styrs av en DCC-tillbehörsadress. När decodern tar emot ett DCC-kommando för en tilldelad adress rör den servonet smidigt till den lagrade positionen för det kommandotillståndet (RAK eller KRÖKT).

- Att skicka kommandot **RAK** rör servonet till sin lagrade raka ändposition.
- Att skicka kommandot **KRÖKT** rör servonet till sin lagrade krökta ändposition.
- Om reläutvidgningsmoduler är monterade växlar reläkontakterna synkroniserat med servonet för hjärtpunktspolarisering.

Servoändpositioner lagras med lokfunktionsknappar — se [Lagra servopositioner](#-lagra-servopositioner) nedan.

---

## 🛠️ DCC-konfigurationsläge

Decodern stöder ett konfigurationsläge som fungerar helt från din DCC-reglage — ingen dator, ingen CV-programmerare krävs.

För att aktivera konfigurationsläge, välj lokadress **9999** på ditt reglage och ställ **F0, F1 och F2 alla på OFF**. Decodern aktiverar konfigurationsläget och accepterar funktionsknappkommandon.

När du är i konfigurationsläge, använd funktionstangenterna (F1–F8) för att ställa in alternativ enligt beskrivningen i avsnitten nedan. Tryck på **F0 = OFF** för att avsluta och återgå till normal drift.

---

## 🛠️ Knappkonfigurationsläge

Kortet har två fysiska knappar: **CONFIGURE** och **TOGGLE**.

- **CONFIGURE** — aktiverar konfigurationsläge direkt, utan behov av ett reglage. Decodern svarar med LED-återkoppling som indikerar den aktiva inställningen.
- **TOGGLE** — växlar manuellt den aktuellt valda servoutgången mellan dess två lagrade positioner. Användbart för att testa rörelsen och justera ändpositioner.

---

## 🌟 Lagra servopositioner
I körläget, använd dessa funktioner för att programmera:

- **F1 = ON ➔** Spara aktuell position som *KRÖKT*  
- **F2 = ON ➔** Spara aktuell position som *RAK*  
- **F3 = ON ➔** Invertera hjärtpunktrelä *(endast 6-relämodell)*  
- **F0 = OFF ➔** Avsluta körläget  

---

## 🚗 Lokfunktionslägen
I konfigurationsläget kan du välja att styra decodern med lokfunktionstangenter istället för tillbehörskommandon.

- **F4 = ON ➔** Inaktivera lokstyrning *(standard)*  
- **F5 = ON ➔** Aktivera lokfunktionsläge *(F1–F8)* — använder 1 adress  
- **F6 = ON ➔** Aktivera 4-funktionsläge *(F1–F4)* — använder 2 adresser  

Det möjliggör ultrasnabb växling med reglage som Roco Lokmaus eller Multimaus.

---

## ⚖️ Adressoffset
För att kompensera för Rocos offset på 4, använd:

- **F7 = ON ➔** Aktivera 4-adressoffset  

---

## ⏰ Auto-växlingsläge
Aktivera automatisk växling av en vald motor:

- **F8 = ON ➔** Motorn växlar var 5:e sekund  
  - Hastigheten styrs av reglaget  
  - Reglagets riktning spelar ingen roll  
  - Reglage 0 = långsamt, Max = snabbt  

I detta läge är motorn inte längre slavad till reglagets funktionstangenter.

---

## 📊 Sammanfattning
- Använd knapparna för direkt inställning och servoreglering  
- Använd DCC-lokadress **9999** med **F0, F1, F2 OFF** för att aktivera konfigurationsläge  
- Använd **F1/F2** för att lagra servopositioner  
- Använd **F4–F8** för att aktivera lokfunktionsstyrning, adressoffset eller växlingslägen  

Alla OS-Servo-Decoders delar detta gränssnitt och denna logik.  
Ingen dator behövs. Inga CV:er. Bara koppla det, adressera det och kör.

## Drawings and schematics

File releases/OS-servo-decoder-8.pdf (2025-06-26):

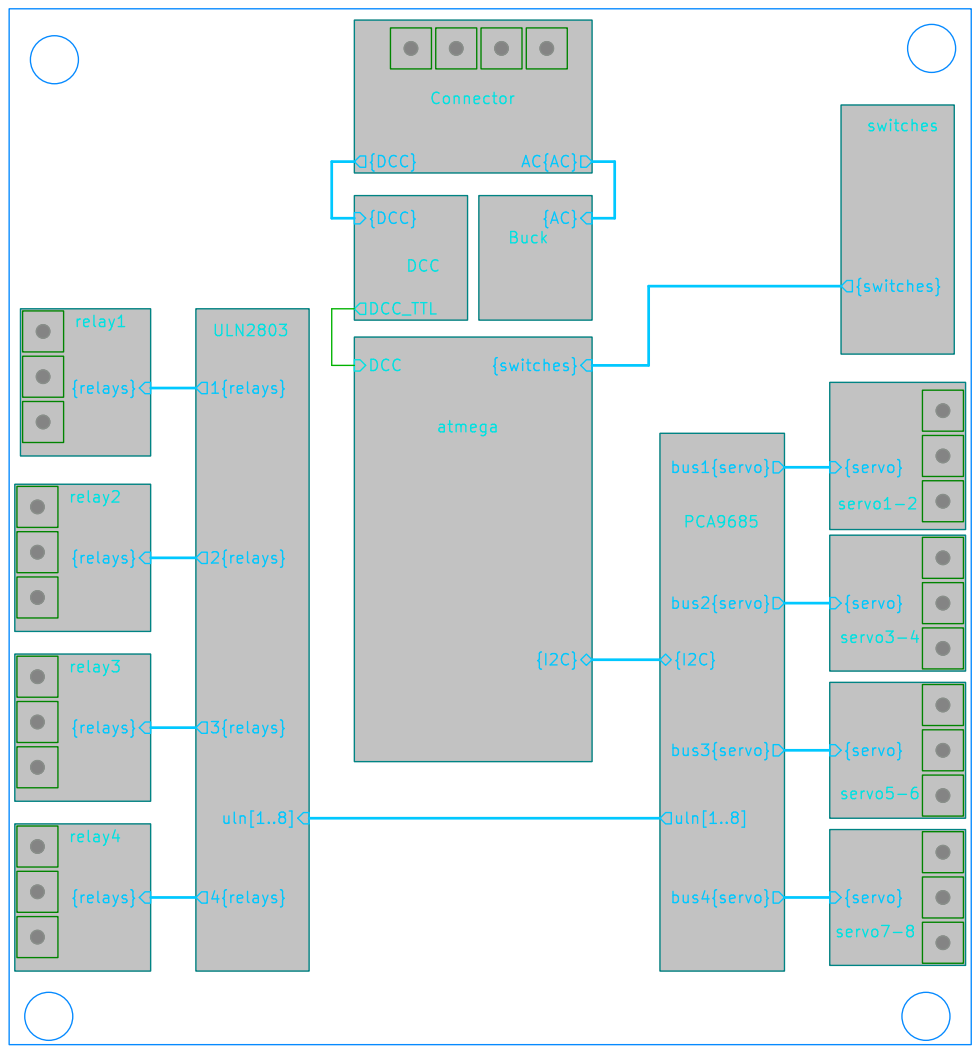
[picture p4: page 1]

{servo} servo5-6

{servo} servo7-8

Id: 1/16 Title: File: OS-servo-decoder-8.kicad_sch Sheet: /

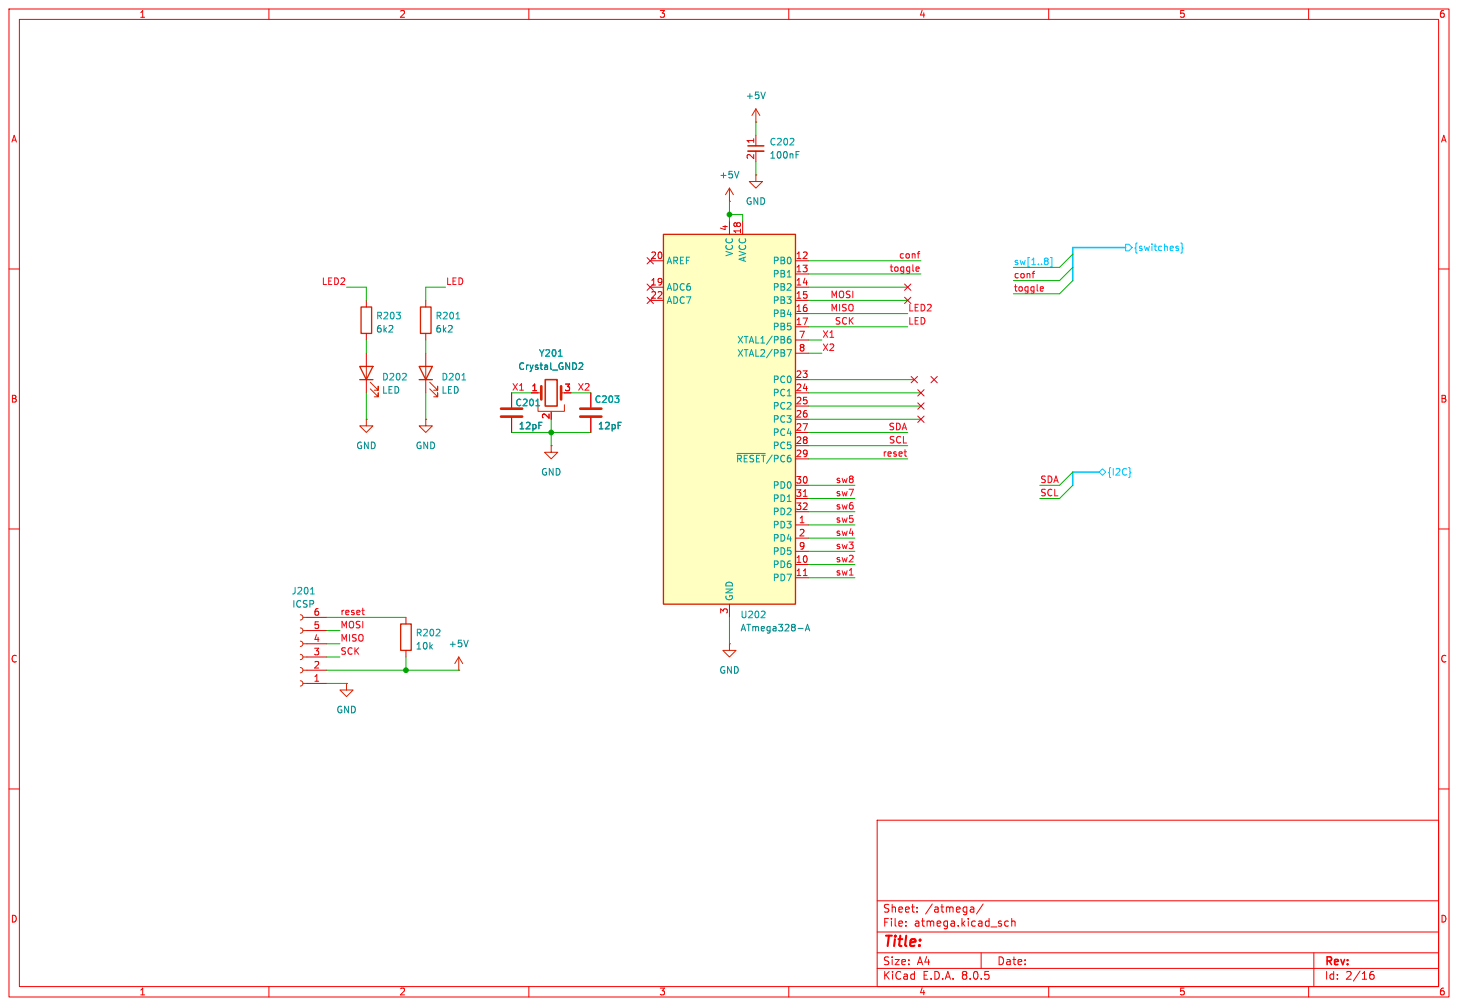
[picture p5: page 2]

reset SCL SDA MOSI

Id: 2/16 Title: File: atmega.kicad_sch Sheet: /atmega/ GND

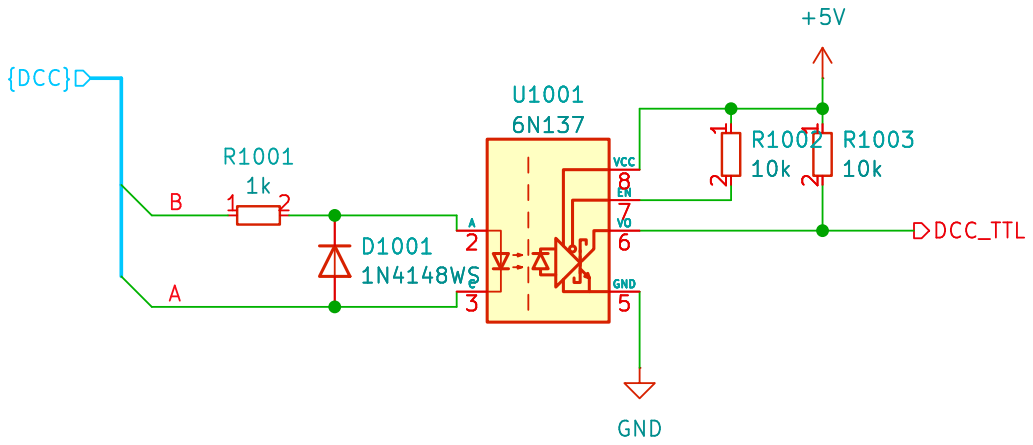
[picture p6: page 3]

Id: 3/16 Title: File: DCC.kicad_sch Sheet: /DCC/

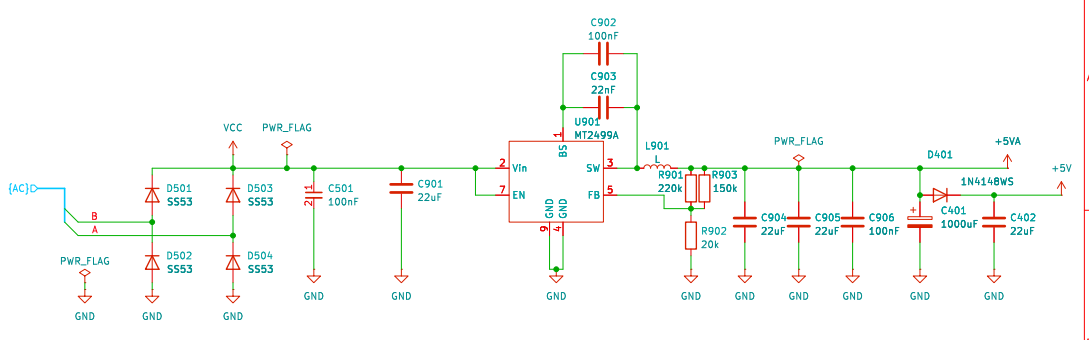
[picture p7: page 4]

Id: 5/16 Title: File: Buck.kicad_sch Sheet: /Buck/

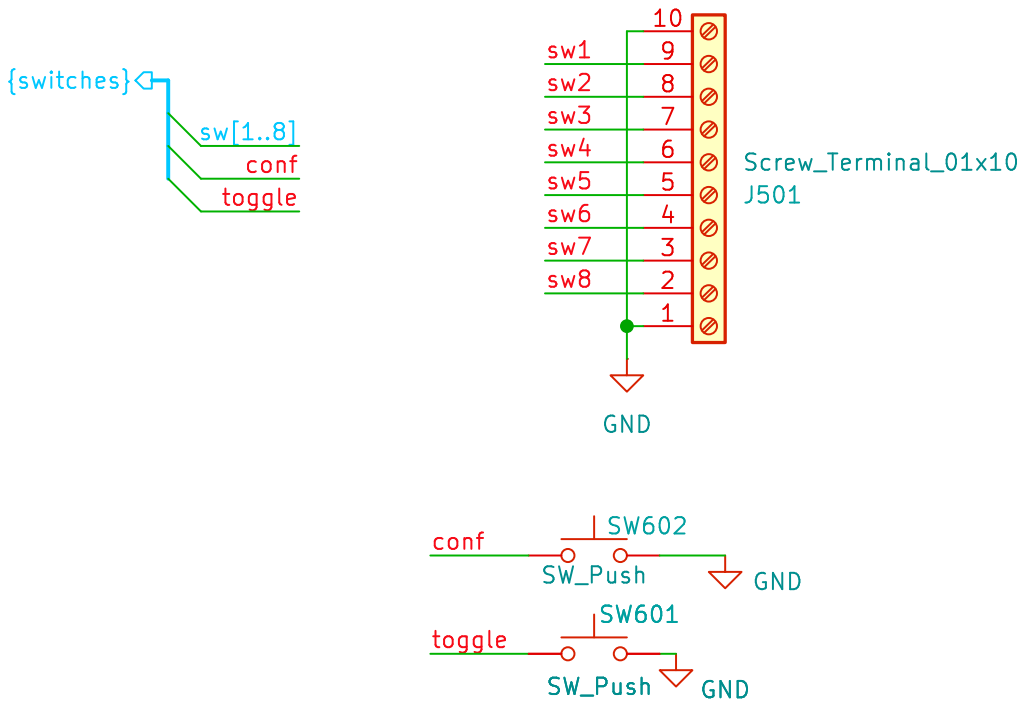
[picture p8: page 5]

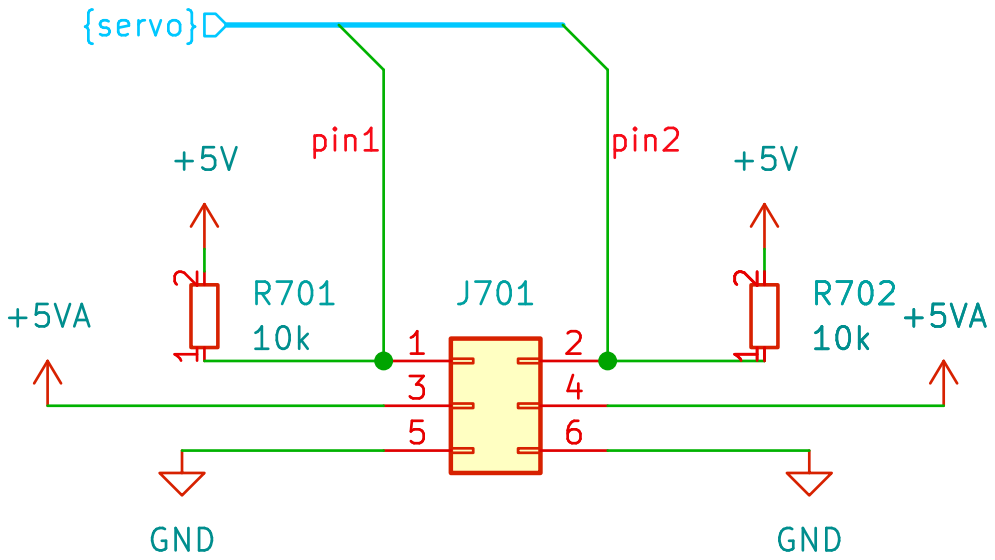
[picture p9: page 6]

Id: 7/16 Title: File: servo.kicad_sch Sheet: /servo1-2/

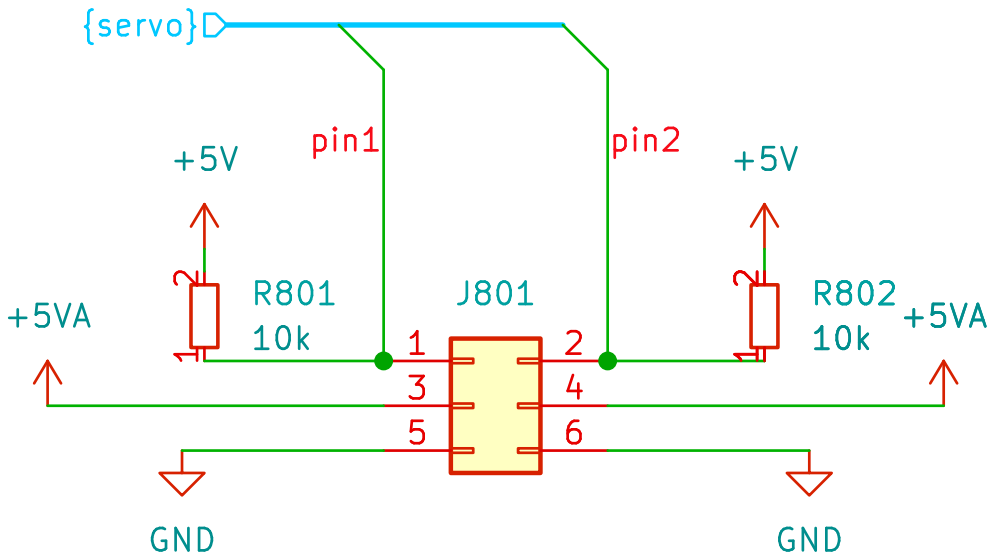
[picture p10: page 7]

Id: 8/16 Title: File: servo.kicad_sch Sheet: /servo3-4/

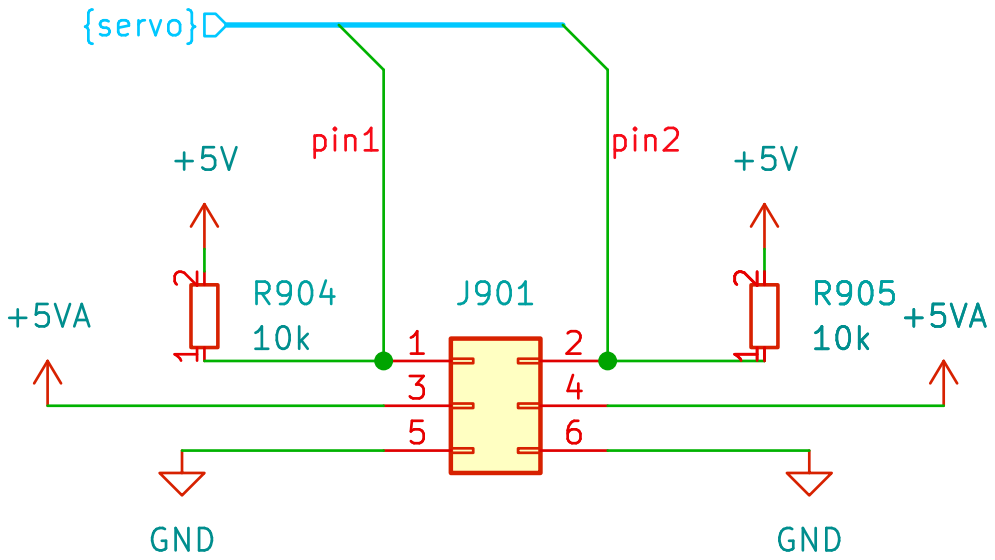
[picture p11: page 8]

Id: 9/16 Title: File: servo.kicad_sch Sheet: /servo5-6/

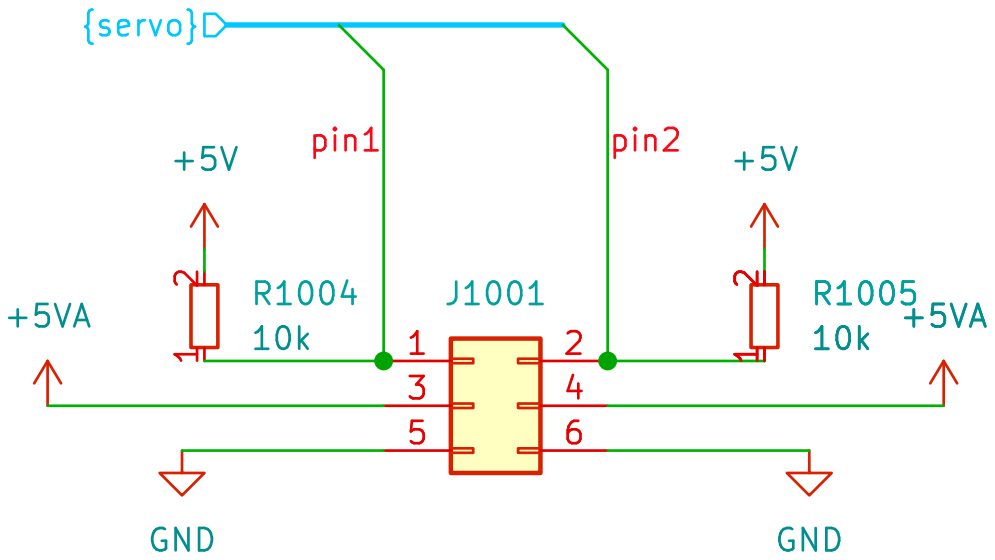
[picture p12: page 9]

Id: 10/16 Title: File: servo.kicad_sch Sheet: /servo7-8/

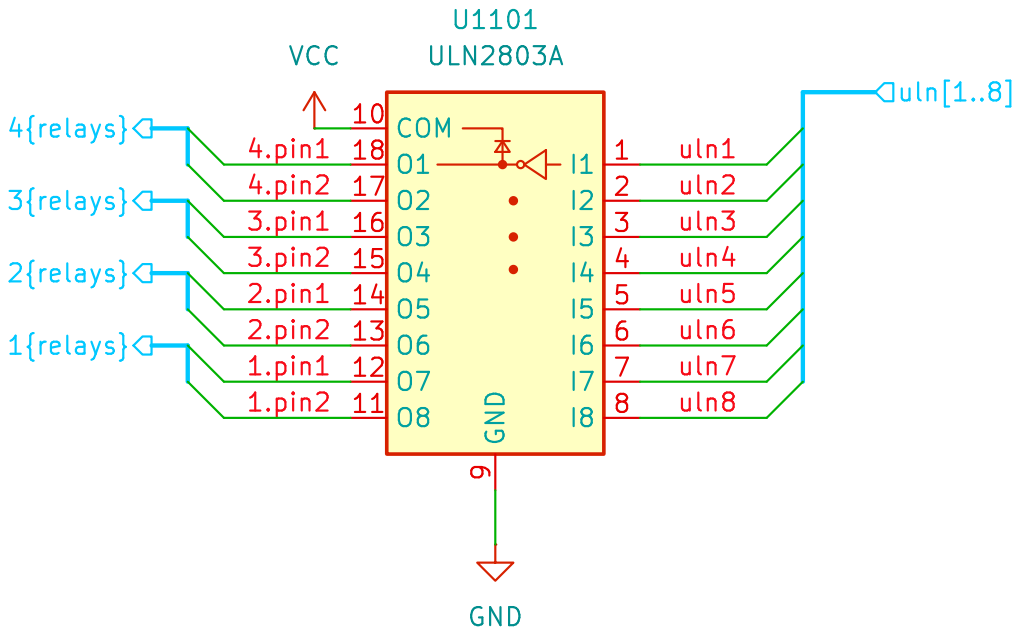
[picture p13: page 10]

Id: 11/16 Title: File: ULN2803.kicad_sch Sheet: /ULN2803/

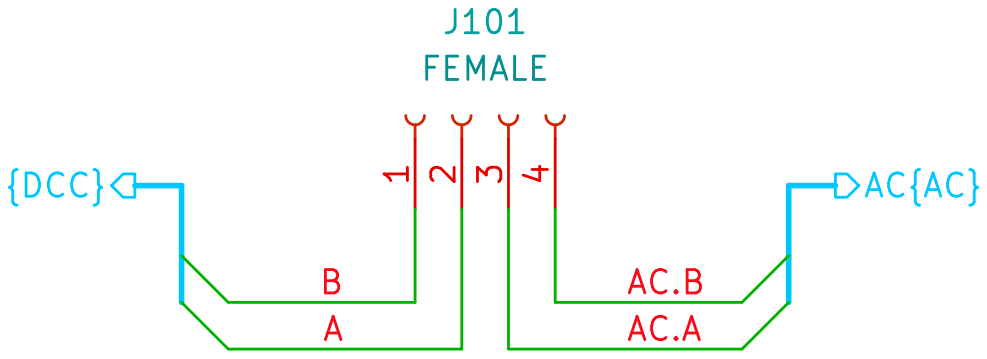
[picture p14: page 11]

Id: 11/16 Title: File: Connector.kicad_sch Sheet: /Connector/

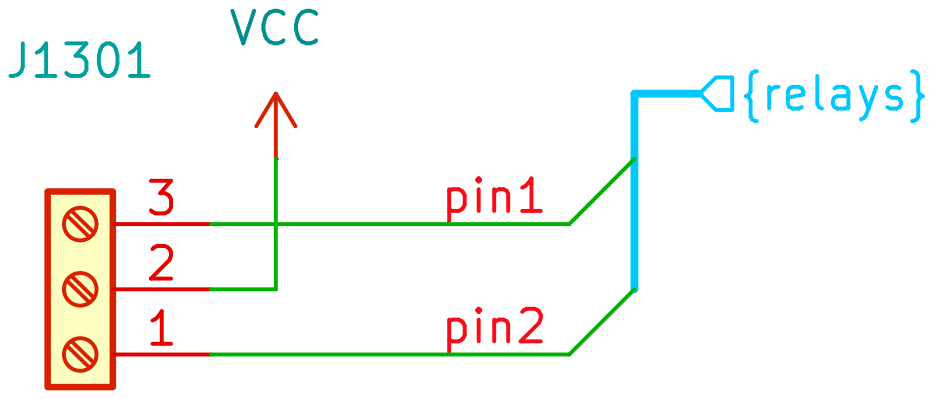
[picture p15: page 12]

Id: 12/16 Title: File: relayConnector.kicad_sch Sheet: /relay1/


Id: 13/16 Title: File: relayConnector.kicad_sch Sheet: /relay2/


Id: 14/16 Title: File: relayConnector.kicad_sch Sheet: /relay3/


Id: 15/16 Title: File: relayConnector.kicad_sch Sheet: /relay4/


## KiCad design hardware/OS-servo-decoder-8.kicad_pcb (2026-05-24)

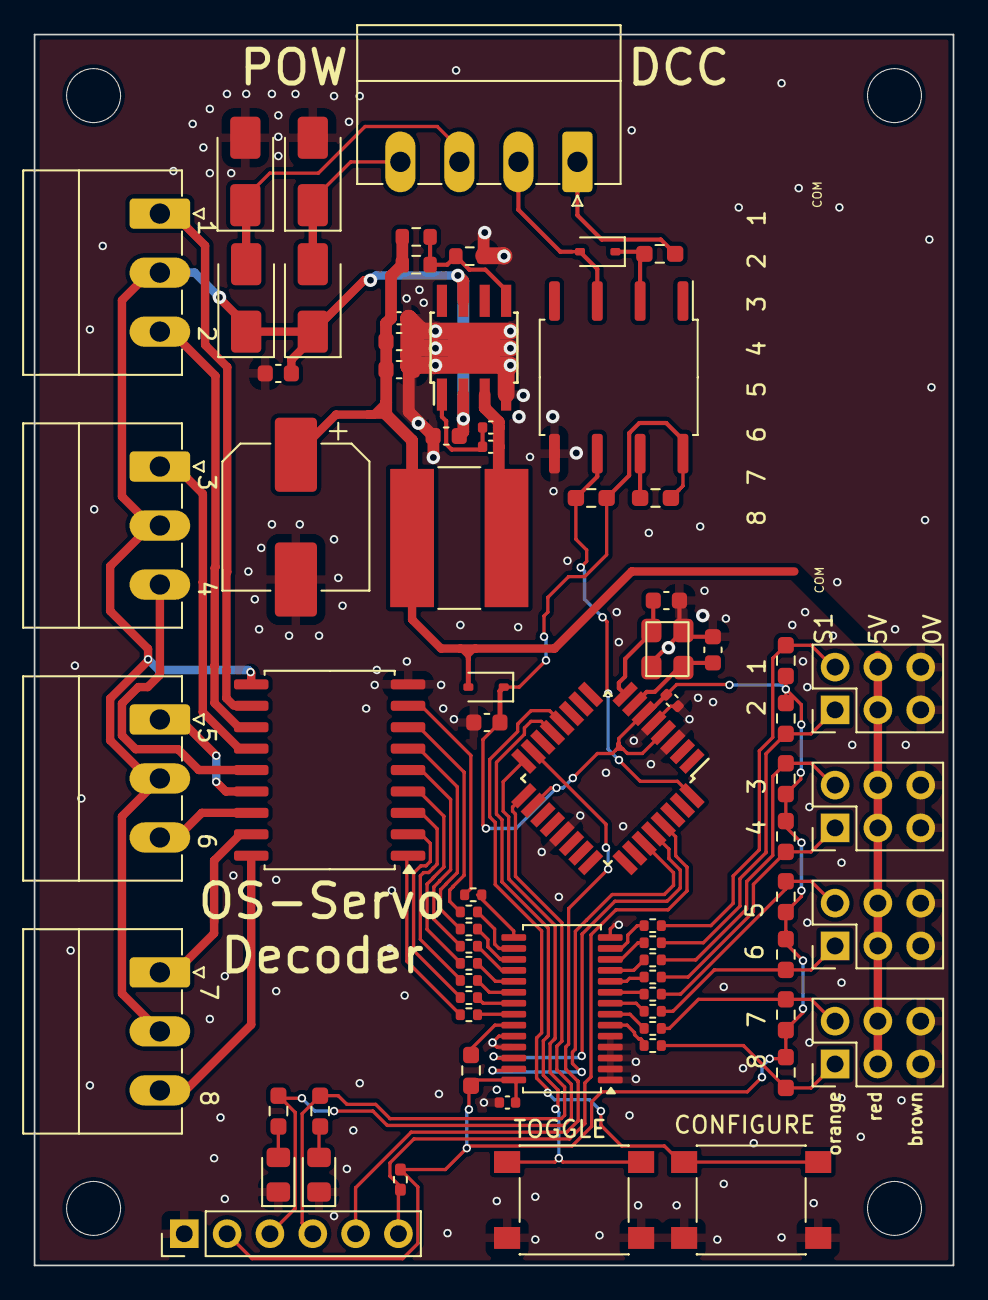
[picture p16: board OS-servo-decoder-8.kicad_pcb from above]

Board: 2 copper layers, 54.5 x 73.0 mm, 74 parts (0 on the bottom side), 67 nets.

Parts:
C201, C203: 12pF; C_0603_1608Metric
C202, C902, C906, C1601: 100nF; C_0402_1005Metric
C401: 1000uF; CP_Elec_8x10.5
C402, C901, C904, C905: 22uF; C_0603_1608Metric
C501: 100nF; C_0603_1608Metric
C903: 22nF; C_0402_1005Metric
D201, D202: LED; LED_0805_2012Metric_Pad1.15x1.40mm_HandSolder
D401, D1001: 1N4148WS; D_SOD-323
D501, D502, D503, D504: SS53; D_SMA
J101: FEMALE; PhoenixContact_MC_1,5_4-G-3.5_1x04_P3.50mm_Horizontal
J201: ICSP; PinHeader_1x06_P2.54mm_Vertical
J401, J1301, J1401, J1501: Screw_Terminal_01x03; PhoenixContact_MC_1,5_3-G-3.5_1x03_P3.50mm_Horizontal
J701, J801, J901, J1001: Conn_02x03_Odd_Even; PinHeader_2x03_P2.54mm_Vertical
L901: L; L_Bourns-SRN8040_8x8.15mm
R201, R203: 6k2; R_0603_1608Metric_Pad0.98x0.95mm_HandSolder
R202: 10k; R_0402_1005Metric_Pad0.72x0.64mm_HandSolder
R701, R702, R801, R802, R904, R905, R1002, R1003, R1004, R1005, R1601: 10k; R_0603_smalltext
R901: 220k; R_0603_1608Metric
R902: 20k; R_0603_1608Metric
R903: 150k; R_0603_1608Metric
R1001: 1k; R_0603_smalltext
R1602, R1603, R1604, R1605, R1606, R1607, R1608, R1609, R1610, R1611, R1612, R1613, R1614, R1615, R1616, R1617: 220R; R_0402_1005Metric
SW601, SW602: SW_Push; tactile_SMD_6mm
U202: ATmega328-A; TQFP-32_7x7mm_P0.8mm
U901: MT2499A; TI_SO-PowerPAD-8
U1001: 6N137; SOP-8_6.62x9.15mm_P2.54mm
U1101: ULN2803A; SOIC-18W_7.5x11.6mm_P1.27mm
U1601: PCA9685PW; TSSOP-28_4.4x9.7mm_P0.65mm
Y201: Crystal_GND2; crystal_arduino

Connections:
+5V: C202.1, C402.1, C1601.1, D401.1 (K), J201.2, R202.2, R701.2, R702.2, R801.2, R802.2, R904.2, R905.2, R1002.1, R1003.1, R1004.2, R1005.2, R1601.1, U202.4 (VCC), U202.6 (VCC), U202.18 (AVCC), U1001.8 (VCC), U1601.28 (VDD)
+5VA: C401.1, C904.1, C905.1, C906.1, D401.2 (A), J701.3, J701.4, J801.3, J801.4, J901.3, J901.4, J1001.3, J1001.4, L901.2, R901.1, R903.2
/Buck/A: D503.2 (A), D504.1 (K), J101.3
/Buck/B: D501.2 (A), D502.1 (K), J101.4
/Connector/A: D1001.2 (A), J101.2, U1001.3 (C)
/Connector/B: J101.1, R1001.1
/DCC/DCC_TTL: R1003.2, U202.32 (PD2), U1001.6 (VO)
/PCA9685/SCL: U202.28 (PC5), U1601.26 (SCL)
/PCA9685/SDA: U202.27 (PC4), U1601.27 (SDA)
/PCA9685/bus1.pin1: J701.1, R701.1, R1608.2
/PCA9685/bus1.pin2: J701.2, R702.1, R1609.2
/PCA9685/bus2.pin1: J801.1, R801.1, R1606.2
/PCA9685/bus2.pin2: J801.2, R802.1, R1607.2
/PCA9685/bus3.pin1: J901.1, R904.1, R1604.2
/PCA9685/bus3.pin2: J901.2, R905.1, R1605.2
/PCA9685/bus4.pin1: J1001.1, R1004.1, R1602.2
/PCA9685/bus4.pin2: J1001.2, R1005.1, R1603.2
/PCA9685/uln1: R1617.2, U1101.1 (I1)
/PCA9685/uln2: R1616.2, U1101.2 (I2)
/PCA9685/uln3: R1615.2, U1101.3 (I3)
/PCA9685/uln4: R1614.2, U1101.4 (I4)
/PCA9685/uln5: R1613.2, U1101.5 (I5)
/PCA9685/uln6: R1612.2, U1101.6 (I6)
/PCA9685/uln7: R1611.2, U1101.7 (I7)
/PCA9685/uln8: R1610.2, U1101.8 (I8)
/ULN2803/1.pin1: J1301.3, U1101.12 (O7)
/ULN2803/1.pin2: J1301.1, U1101.11 (O8)
/ULN2803/2.pin1: J401.3, U1101.14 (O5)
/ULN2803/2.pin2: J401.1, U1101.13 (O6)
/ULN2803/3.pin1: J1401.3, U1101.16 (O3)
/ULN2803/3.pin2: J1401.1, U1101.15 (O4)
/ULN2803/4.pin1: J1501.3, U1101.18 (O1)
/ULN2803/4.pin2: J1501.1, U1101.17 (O2)
/atmega/LED: J201.3, R201.1, U202.17 (PB5)
/atmega/LED2: J201.4, R203.1, U202.16 (PB4)
/atmega/MOSI: J201.5, U202.15 (PB3)
/atmega/X1: C201.2, U202.7 (XTAL1/PB6), Y201.1
/atmega/X2: C203.2, U202.8 (XTAL2/PB7), Y201.3
/atmega/conf: SW602.2, U202.12 (PB0)
/atmega/reset: J201.6, R202.1, U202.29 (~RESET/PC6)
/atmega/toggle: SW601.2, U202.13 (PB1)
GND: C201.1, C202.2, C203.1, C401.2, C402.2, C501.2, C901.2, C904.2, C905.2, C906.2, C1601.2, D201.1 (K), D202.1 (K), D502.2 (A), D504.2 (A), J201.1, J701.5, J701.6, J801.5, J801.6, J901.5, J901.6, J1001.5, J1001.6, R902.2, SW601.1, SW602.1, U202.3 (GND), U202.5 (GND), U202.21 (GND), U901.4 (GND), U901.9 (GND), U1001.5 (GND), U1101.9 (GND), U1601.1 (A0), U1601.2 (A1), U1601.3 (A2), U1601.4 (A3), U1601.5 (A4), U1601.14 (VSS), U1601.24 (A5), U1601.25 (EXTCLK), Y201.2 (GND), Y201.4 (GND)
unnamed: D201.2 (A), R201.2
unnamed: D202.2 (A), R203.2
unnamed: D1001.1 (K), R1001.2, U1001.2 (A)
unnamed: C902.1, C903.1, U901.1 (BS)
unnamed: R901.2, R902.1, R903.1, U901.5 (FB)
unnamed: C902.2, C903.2, L901.1, U901.3 (SW)
unnamed: R1002.2, U1001.7 (EN)
unnamed: R1602.1, U1601.6 (LED0)
unnamed: R1603.1, U1601.7 (LED1)
unnamed: R1604.1, U1601.8 (LED2)
unnamed: R1605.1, U1601.9 (LED3)
unnamed: R1606.1, U1601.10 (LED4)
unnamed: R1607.1, U1601.11 (LED5)
unnamed: R1608.1, U1601.12 (LED6)
unnamed: R1609.1, U1601.13 (LED7)
unnamed: R1610.1, U1601.15 (LED8)
unnamed: R1611.1, U1601.16 (LED9)
unnamed: R1612.1, U1601.17 (LED10)
unnamed: R1613.1, U1601.18 (LED11)
unnamed: R1614.1, U1601.19 (LED12)
unnamed: R1615.1, U1601.20 (LED13)
unnamed: R1616.1, U1601.21 (LED14)
unnamed: R1617.1, U1601.22 (LED15)
unnamed: R1601.2, U1601.23 (~OE)
VCC: C501.1, C901.1, D501.1 (K), D503.1 (K), J401.2, J1301.2, J1401.2, J1501.2, U901.2 (Vin), U901.7 (EN), U1101.10 (COM)

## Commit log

2025-06-13 added initial files
    [Buck.kicad_sch, DCC.kicad_sch, D_bridge.kicad_sch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]
2025-06-18 deleted source code in favor of sub module
    [OS-servo-decoder-8.kicad_pcb]
2025-06-18 Add submodule OS-Servo-Decoder-Core in software/
2025-06-26 update board file, made similar to OS solenoid decoder
    [Buck.kicad_sch, Connector.kicad_sch, DCC.kicad_sch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]
2025-07-22 added manual and picture
    [Buck.kicad_sch, Connector.kicad_sch, DCC.kicad_sch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]
2025-10-27 removed obsolete build and upload files
    [BOM-OS-servo-decoder-8.csv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]
2026-05-24 added translations
    [OS-servo-decoder-8.kicad_pcb, switches.kicad_sch]
